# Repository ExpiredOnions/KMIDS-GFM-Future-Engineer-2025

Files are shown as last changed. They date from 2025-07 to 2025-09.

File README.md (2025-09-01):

# Hello! We are **Team KMIDS-GFM**.


# WRO - Future Engineers - Robotics Project Documentation

## Team Members

- **Chayanon Ninyawee (Garfield)**
- **Supakorn Sunthonthammarat (Pleum)**
- **Thammatouch Chantasarn (Kao)**

We are a team of dedicated students with a passion for robotics and innovation. This repository documents our full engineering process, including design, components used, development, testing, and coding of our robot.

## Table of Contents

<!-- toc -->

- [1. About the Project](#1-about-the-project)
- [2. Mobility Management](#2-mobility-management)
  - [2.1 Drive System](#21-drive-system)
  - [2.2 Steering](#22-steering)
- [3. Power and Sense Management](#3-power-and-sense-management)
  - [3.1 Power Source](#31-power-source)
  - [3.2 Sensor and Camera](#32-sensor-and-camera)
  - [3.3 Processing Units](#33-processing-units)
  - [3.4 Circuit Diagram](#34-circuit-diagram)
- [4. Obstacle Management](#4-obstacle-management)
  - [4.1 Open Challenge](#41-open-challenge)
  - [4.2 Obstacle Challenge](#42-obstacle-challenge)
  - [4.3 Parallel Parking](#43-parallel-parking)
  - [4.4 Extra: Converting Raw Lidar Data to Useful Data](#44-extra-converting-raw-lidar-data-to-useful-data)
- [5. Robot Design](#5-robot-design)
  - [5.1 Robot Images](#51-robot-images)
  - [5.2 Chassis Design](#52-chassis-design)
- [6. Performance Video](#6-performance-video)
- [7. Source Code](#7-source-code)
  - [7.1 Code Structure](#71-code-structure)
  - [7.2 Compilation / Upload Instructions](#72-compilation--upload-instructions)
    - [Dependencies](#dependencies)
    - [Raspberry Pi 5 Build](#raspberry-pi-5-build)
    - [Raspberry Pi Pico 2 Build & Upload](#raspberry-pi-pico-2-build--upload)
- [8. List of Components](#8-list-of-components)
- [9. 3D Printed Parts](#9-3d-printed-parts)
  - [9.1 Chassis & Core Structure](#91-chassis--core-structure)
  - [9.2 Motor & Transmission](#92-motor--transmission)
  - [9.3 Wheel & Axle Components](#93-wheel--axle-components)
  - [9.4 Steering Linkages](#94-steering-linkages)
  - [9.5 Miscellaneous](#95-miscellaneous)

<!-- tocstop -->

______________________________________________________________________

## 1. About the Project

This project focuses on designing, building, and programming an autonomous robot capable of completing a series of complex obstacle challenges as part of the WRO Future Engineers competition.

Team KMIDS-GFM was inspired by the challenge of applying engineering principles and problem-solving skills to creatively and efficiently solve complex problems. Pushing forward with our passion for innovation and hands-on learning.

Our goal is to design and build a reliable and efficient system that demonstrates our technical and collaborative skills while serving as a learning experience. We followed a systematic process, including brainstorming, researching, prototyping, testing, and iterating. We maintained detailed documentation for ease of knowledge sharing and a smoother workflow throughout the project.

Our robot is engineered using a custom modular chassis in a rear-wheel drive configuration, controlled using a Raspberry Pi 5 and a Raspberry Pi Pico 2. It utilises a combination of an LIDAR sensor and a fish-eye lens camera to provide an advanced system for obstacle detection and navigation.

Our objective is to create an intelligent robot that is capable of navigating through obstacles with pinpoint precision and speed.

______________________________________________________________________

## 2. Mobility Management

- **Drive System:** 2-wheel differential drive (rear wheels).
- **Steering:** Front-wheel steering using S0004m servo.

### 2.1 Drive System

[Motor: N20 Motor](https://shopee.co.th/product/627316253/26413874397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) 

<table>
  <tr>
    <td align="center" width="300" >
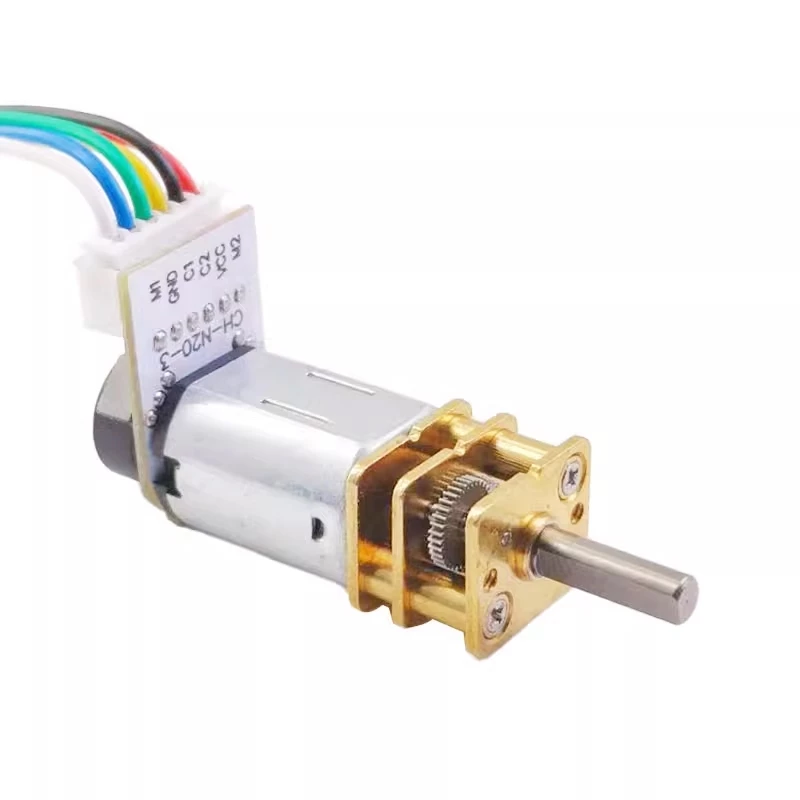
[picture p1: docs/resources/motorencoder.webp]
      
    </td>
    <td>
      <h3>Specifications:</h3>
      <ul>
        <li>Voltage: 6V </li>
        <li>No-load Speed: 500RPM </li>
        <li>Stall Torque 0.15kg-cm</li>
        <li>Current: 0.023A</li>
        <li>Gear Ratio: 1:100</li>
      </ul>
    </td>
  </tr>
</table>

**Reason for Selection:**

- It is compact and lightweight, allowing us to fit it into our robot easily.
- Provides moderate torque that is more than enough for the flat arena.
- Easy to use on the robot and integrate with other parts.

The N20 motor is equipped with an encoder to provide precise motion feedback, ensuring the robot’s movements are accurate. The motor drives the rear wheels through a LEGO differential gear system, which allows the robot to maintain smooth and balanced turns even at higher speeds. By distributing torque between the two wheels, the differential minimises wheel slip and ensures stability during sharp manoeuvres.
The integration of encoders with the N20 motors provides real-time feedback for closed-loop control, enabling precise speed regulation and consistent lap performance. Although the torque of the N20 is modest, the combination with the differential gear makes it well-suited for the flat and predictable competition arena, striking a balance between efficiency, stability, and mechanical simplicity.

**Mounting:**

- Installed using 3D-printed motor clamps screwed to a detachable motor plate that is placed above the differential gear compartment. This will allow for future changes to accommodate bigger motors and gears. (./FreeCAD-Files/Assembly/mesh_export/MotorPlate_1x.stl)
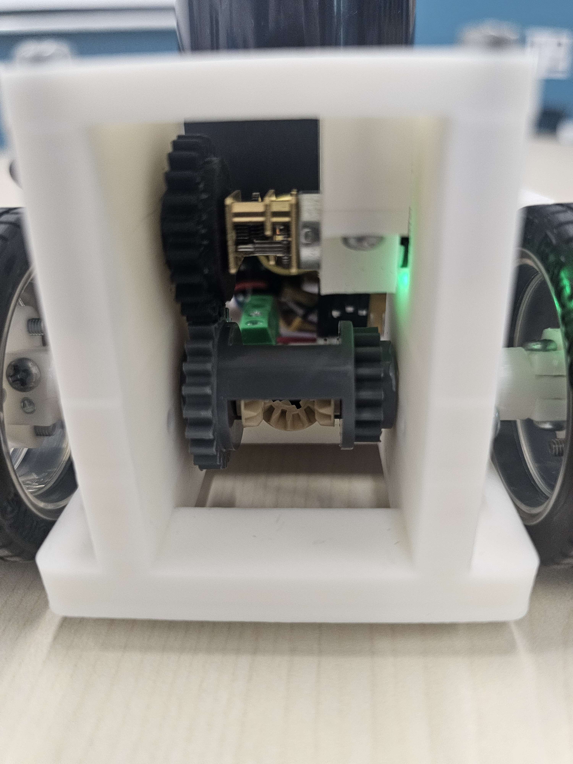
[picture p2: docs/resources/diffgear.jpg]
diff gear
  
- Wires connected to Raspberry Pi Pico 2.
- Rubber wheels are screwed onto the motor shaft.

**Considerations:**
To reach a faster speed, we can upgrade the N20 motor to the N30, which is the easiest upgrade, providing an overall improvement in speed and torque. However, the N30 motor is typically larger and such, might need extra modifications to the robot's chassis and motor clamp to fit properly. It also generally operates at higher voltages and currents, so the power supply needs to be modified to support this upgrade.

### 2.2 Steering

We considered many steering systems, but following our design principle of precision, we decided to implement Ackermann steering geometry to better replicate the precise turning behaviour of real-world vehicles. Unlike simpler systems, Ackermann steering has the advantage of smoother turns by moving each wheel at different angles in a turn, reducing the slippage of the tires and improving turn accuracy.

The fundamental principle of Ackermann geometry involves positioning the steering linkage so that a line drawn through both front wheels intersects the rear axle of the robot.

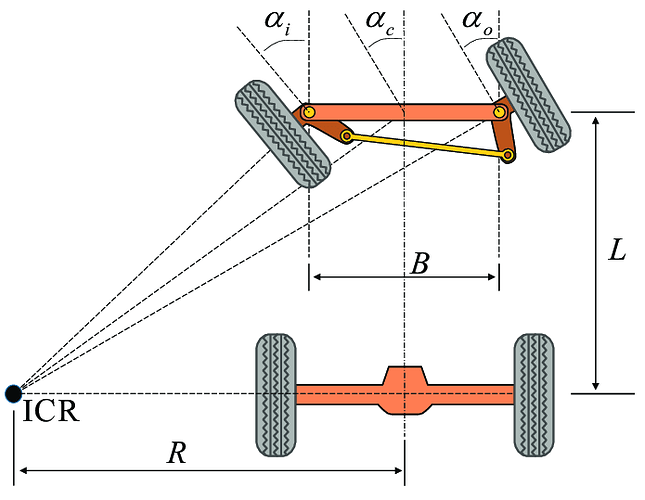
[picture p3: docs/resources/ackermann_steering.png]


While this steering geometry is complex to implement, we believe that the advantages it provides are important, especially in obstacle navigation and parking, where precise control and minimized turning radius are essential. It enables smoother manoeuvring and accurate alignment in narrower spaces.

Our implementation involves designing a custom 3D-printed Ackermann steering mechanism. Using CAD to design the mechanism gives us the flexibility to experiment with pivot points and steering angles. Although true Ackermann geometry is difficult to implement at our robot's scale, we tried to approximate the behavior iteratively by adjusting the servo horns and angles in CAD and prototyping by making smaller changes if it doesn't suit our desired behavior.

**Calibration and Implementation**

To make sure the steering angle performed correctly, we carried out an iterative calibration process:

- We manually adjusted the servo horn angle and linkage positions step by step in FreeCAD until the wheels aligned at the desired steering angle.
- After each adjustment, we observed whether the wheels tracked correctly in both directions.
- Once the optimal angle is reached, we make sure to model the steering mechanism around the angle.



[Servo: S0004m](https://shopee.co.th/%E0%B9%80%E0%B8%8B%E0%B8%AD%E0%B8%A3%E0%B9%8C%E0%B9%82%E0%B8%A7%E0%B8%94%E0%B8%B4%E0%B8%88%E0%B8%B4%E0%B8%97%E0%B8%B1%E0%B8%A5-%E0%B8%82%E0%B8%9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) 

<table>
  <tr>
    <td align="center" width="300" >
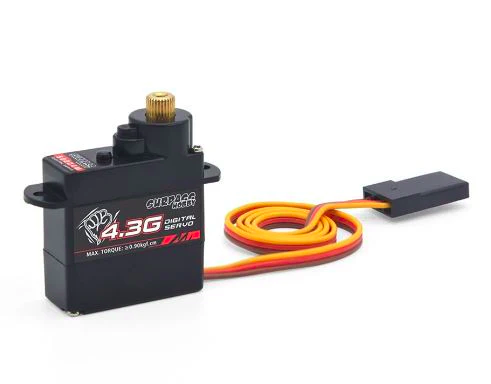
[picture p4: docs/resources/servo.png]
      
    </td>
    <td> 
      <h3>Specifications:</h3>
      <ul>
          <li>Rated Torque: 0.6kgf-cm</li>
          <li>Speed: 0.09sec/60°</li>
          <li>Voltage: 5V</li>
          <li>Gearing: Plastic</li>
          <li>Type: Digital </li>
      </ul>
    </td>
  </tr>
</table>

**Reason for Selection:**

- The small size and PWM interface make it easy to control via Raspberry Pi Pico 2.
- It has sufficient torque to steer the front wheels responsively.
- It has balanced speed and stability during turns and lane changes.
- This servo is widely used in hobby robotics, and as such, there is much available documentation and mounting kits.

**Mounting:**

- Screwed directly into a platform plate in front of the chassis into the platform plate.

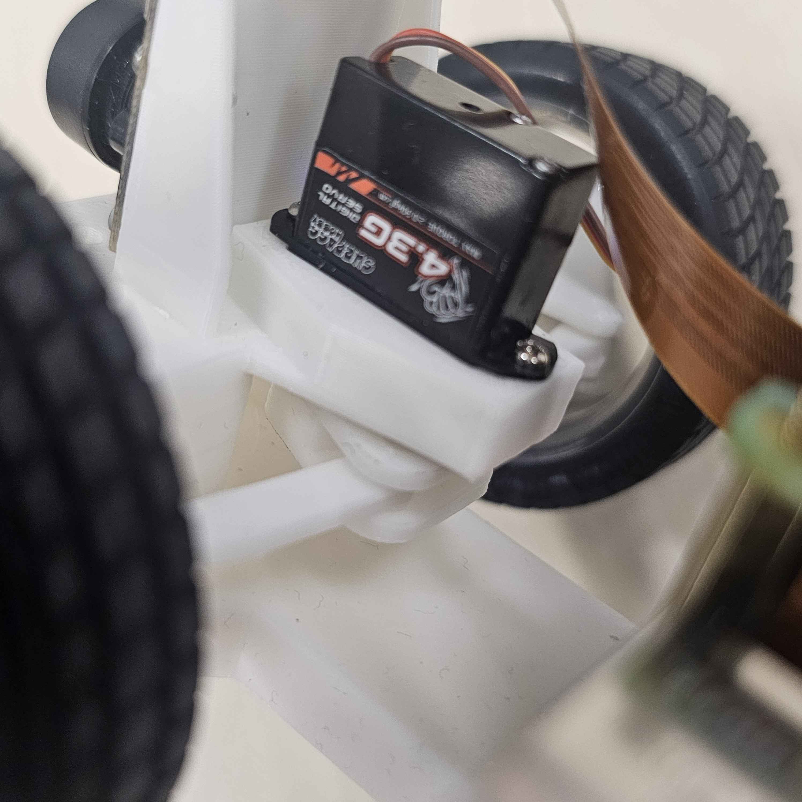
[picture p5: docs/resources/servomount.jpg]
Servo Mounting


**Considerations**
While the servo used is adequate for the task, it can still be replaced with something more precise. We plan to upgrade to a high-resolution digital servo with a narrower deadband and metal gears for more accurate movement. By also integrating a PWM driver such as the PCA9685, we gain 12-bit resolution control, which gives the robot the ability to make finer adjustments than the Raspberry Pi’s native PWM.

______________________________________________________________________

## 3. Power and Sense Management

### 3.1 Power Source

[18650 Lithium-Ion Battery](https://th.cytron.io/p-3.7v-2000mah-li-ion-battery)

<table>
  <tr>
    <td align="center" width="300" >
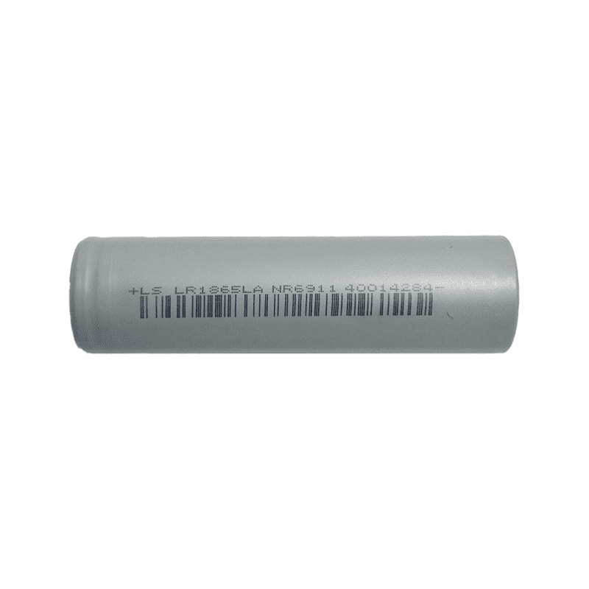
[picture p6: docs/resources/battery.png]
      
    </td>
    <td>
      <h3>Specifications:</h3>
      <ul>
          <li>Capacity: 2000 mAh</li>
          <li>Normal voltage: 3.7V</li>
          <li>Standard discharge: 10A </li>
          <li>Weight: 48g</li>
      </ul>
    </td>
  </tr>
</table>

The power and sensor systems are crucial to the vehicle's ability to navigate the challenges of the competition. For this project, the vehicle is powered by a [EP-0136 Raspberry Pi UPS](https://wiki.52pi.com/index.php?title=EP-0136) (Uninterruptible Power Supply) in our vehicle, with 2x 18650 Lithium-Ion as the energy source. The UPS maintains a stable 5V output to the Raspberry Pi 5 even though there are fluctuations. It also has built-in charging and voltage regulation circuits, allowing continuous operation while also recharging the batteries when external power is connected.
The batteries are connected in series to provide a nominal voltage of 7.4V and a combined capacity of around 4000 mAh, depending on the cells used. This setup is capable of delivering a continuous current of around 20 Amps, which is sufficient to supply to the robot for various tasks. This setup ensures that the Raspberry Pi won't shut down unexpectedly, allowing uninterrupted data processing and decision-making throughout the run.

The motors, however, require a higher voltage — at least 6V, and to ensure reliable performance, the N20 motor power is supplied through a step-up converter that increases 5V to 12V. Because the motor power is separate from the Raspberry Pi, the standard on/off switch could not fully control the system. To solve this, a MOSFET and a 4.4 kΩ resistor were added between the gate and source, with the drain connected to the negative side of the step-up converter. This allows the robot to be safely powered on and off while supplying sufficient power to both the Raspberry Pi and the motors.

The onboard processing unit, the Raspberry Pi 5, serves as the vehicle's brain. Raspberry Pi recommends a 5V 5A power supply. This is well within the limits of what the two batteries can provide.

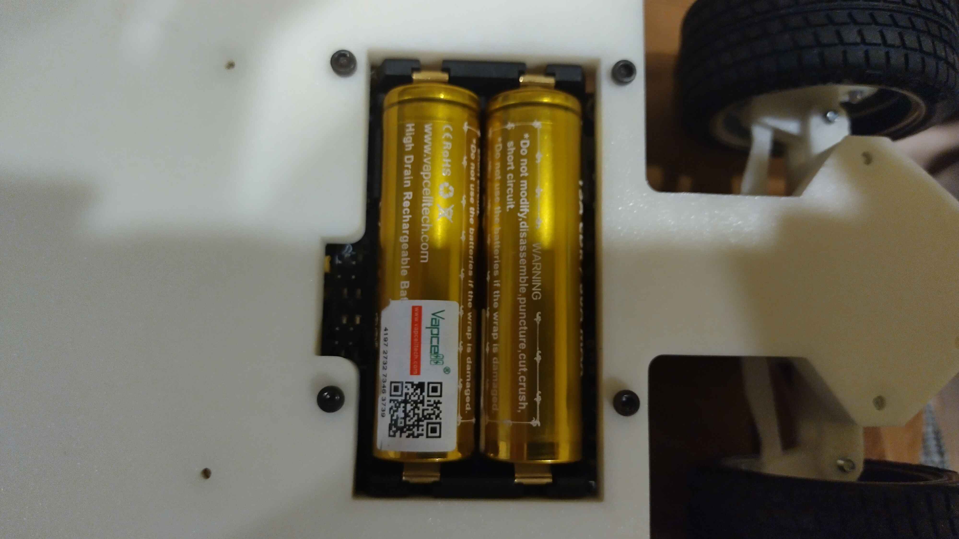
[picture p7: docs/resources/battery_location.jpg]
 

### 3.2 Sensor and Camera

[RPLIDAR C1](https://www.slamtec.com/en/C1)

<table>
  <tr>
    <td align="center" width="300" >
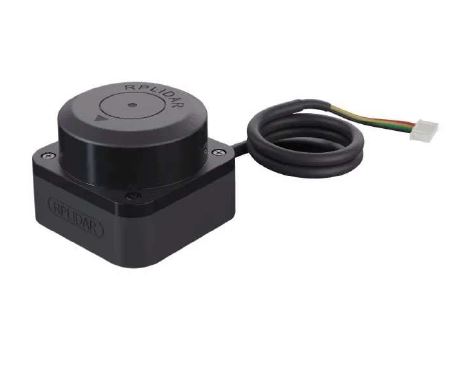
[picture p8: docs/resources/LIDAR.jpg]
      
    </td>
    <td>
      <h3>Specifications:</h3>
      <ul>
        <li>Distance Range:
          <ul>
            <li>White: 0.05~12m (70% Reflectivity)</li>
            <li>Black: 0.05~6m (10% Reflectivity)</li>
          </ul>
        </li>
        <li>Angle Resolution: 0.72°</li>
        <li>Sample Frequency: 8~12Hz (10Hz Typical)</li>
        <li>Range Accuracy: 15mm</li>
        <li>Discharge Rate: 30C</li>
        <br/><br/>
      </ul>
    </td>
  </tr>
</table>

**Reason for Selection:**

- **Precise distance measurement** of obstacles within a wide radius
- **360° scanning** makes it ideal for SLAM (Simultaneous Localisation and Mapping).
- **Compact size and lightweightness** allow easy fitting on our robot.
- **Fast sampling rate** allows real-time mapping and obstacle avoidance.

<!--FIXME: Add LIDAR_mount.png-->

[Fish Eye Lens Raspberry Pi 5MP IR Camera](https://th.cytron.io/p-fish-eye-lense-raspberry-pi-5mp-ir-camera?r=1&language=en-gb&gad_campaignid=18809653822)

<table >
  <tr>
    <td align="center" width="300" >
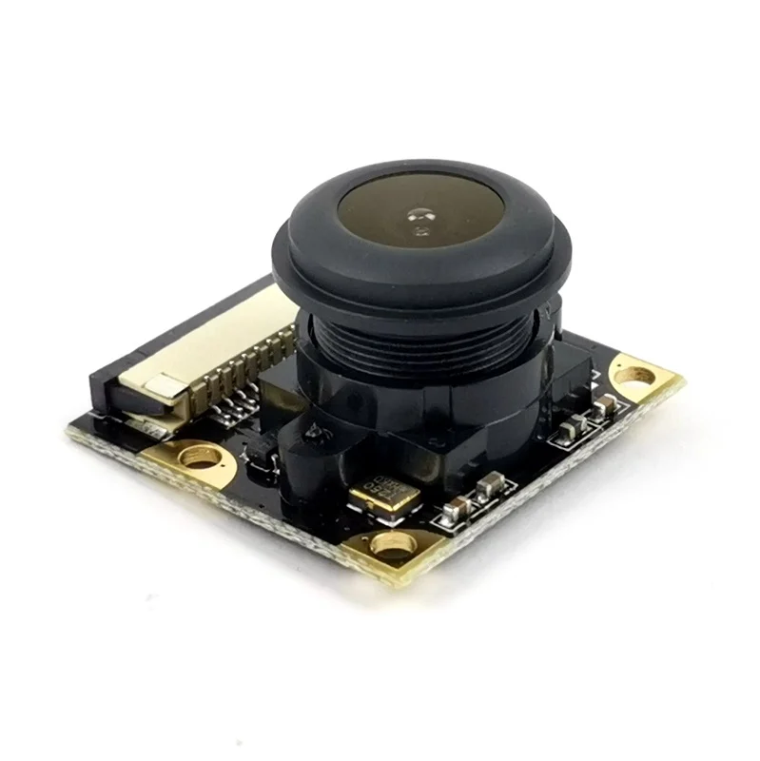
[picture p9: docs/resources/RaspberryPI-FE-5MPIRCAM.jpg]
      
    </td>
    <td >
      <h3>Specifications:</h3>
      <ul>
        <li>Voltage: 6V</li>
        <li>Resolution: 5MP </li>
        <li>Focal Length: Adjustable</li>
        <li>Image Sensor: OV5647</li>
        <li>Aperture: F2.35</li>
      </ul>
    </td>
  </tr>
</table>

**Reason for Selection:**

- **130° wide field of view** captures a large area for tracking.
- **Infrared compatibility** enables low-light vision.
- **High-resolution (5MP)** provides a clear image for the robot.
- **Compact size** fits well on our robot.

This setup allows for a wide-angle view, enhancing environmental awareness during both the Open Challenge and Obstacle Challenge. The camera identifies course elements such as walls, pillars, colored markers, parking spaces, and lane lines.

- Detect and differentiate wall positions.

- Identify pillar colours and types.

- Recognise parking zones.

- Track path lines and boundaries.

### 3.3 Processing Units

[Single Board Computer: Raspberry Pi 5](https://gammaco.com/gammaco/Raspberry_Pi_GB_89RD014.html)

<table>
  <tr>
    <td align="center" width="300" >
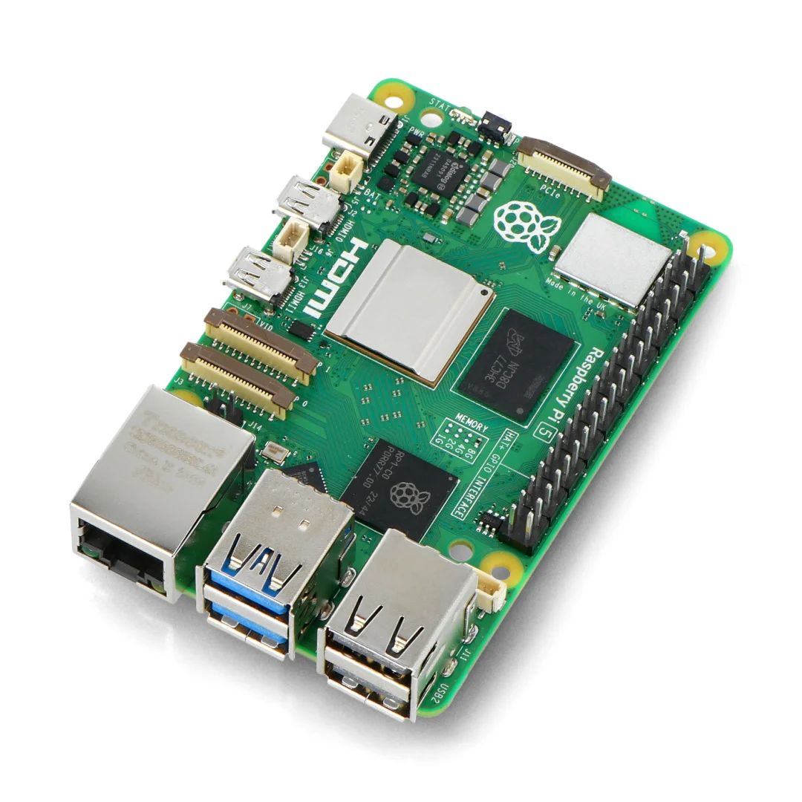
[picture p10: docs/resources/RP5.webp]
INSERT RP5
      
    </td>
    <td>
      <h3>Specifications:</h3>
      <ul>
        <li>Quad-core Arm Cortex-A76 CPU @ 2.4GHz</li>
        <li>8GB LPDDR4X RAM</li>
        <li>Dual 4K HDMI output (60fps)</li>
        <li>PCIe 2.0 support via FPC connector</li>
        <li>2x USB 3.0 ports, 2x USB 2.0 ports</li>
      </ul>
    </td>
  </tr>
</table>

[Raspberry Pi Pico 2](https://th.cytron.io/p-raspberry-pi-pico2-board)

<table>
  <tr>
    <td align="center" width="300" >
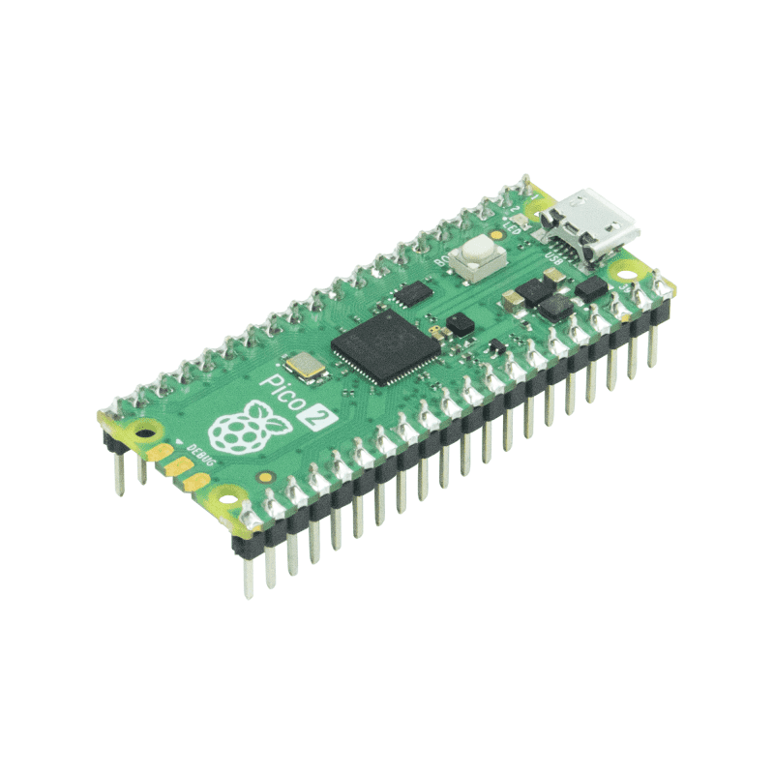
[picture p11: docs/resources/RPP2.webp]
INSERT RPP2
      
    </td>
    <td>
      <h3>Specifications:</h3>
      <ul>
        <li>Dual ARM Cortex-M33</li>
        <li>4 MB QSPI flash memory</li>
        <li>520KB SRAM</li>
        <li>2.4GHz 802.11n wireless LAN</li>
        <li>26 multi-function GPIO pins</li>
      </ul>
    </td>
  </tr>
</table>

### 3.4 Circuit Diagram

**Wiring Diagram:**

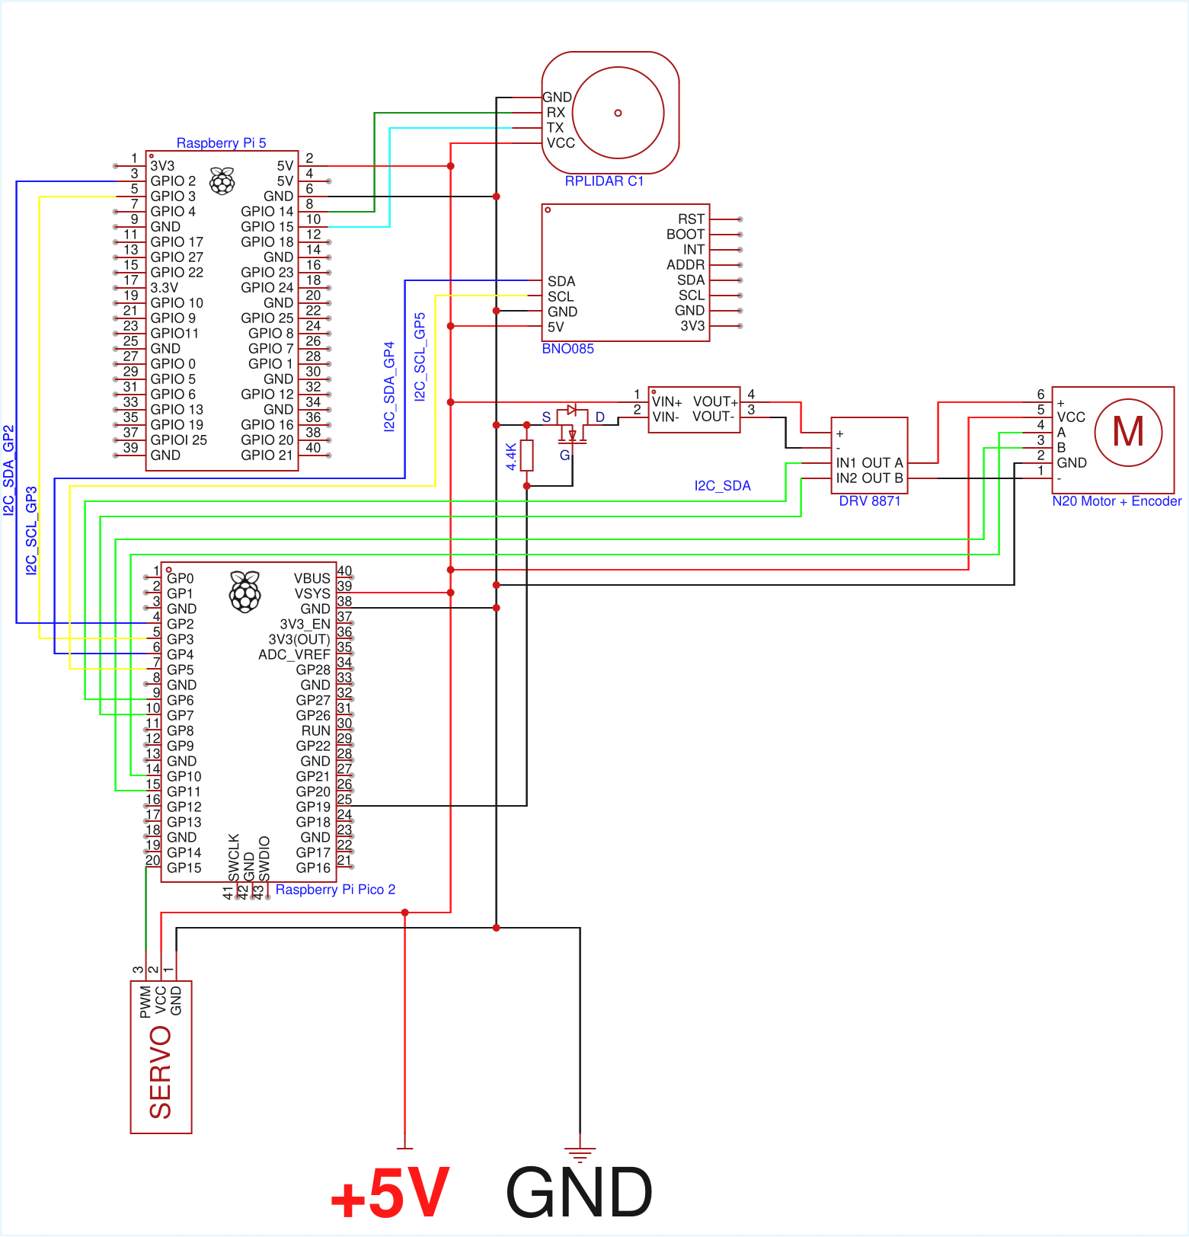
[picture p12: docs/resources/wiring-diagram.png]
Wiring diagram pic


______________________________________________________________________

## 4. Obstacle Management

There are two challenges in this competition:

- The **open challenge** involves the robot completing three full laps around the field without touching the wall. The size of each side of the field and the direction in which the car drives are randomised.
- The **obstacle challenge** requires the robot to complete three laps whilst avoiding the traffic signs. If the sign is red, then the robot must traverse on the right side and if the pillar is green, the robot must traverse on the left. The direction in which the car drives and the placement of the signs are randomised. After the third lap, the car must find the parking area and park in the area without touching the surroundings barriers around it.

Our implementation relies heavily on the RPLIDAR C1 sensor and the fish-eye lens camera for continuous environment scanning, which helps the algorithm decide the movement of the robot.

We divide the strategy into three phases:

- Open Challenge
- Obstacle Challenge
- Parallel Parking Manoeuvre

### 4.1 Open Challenge

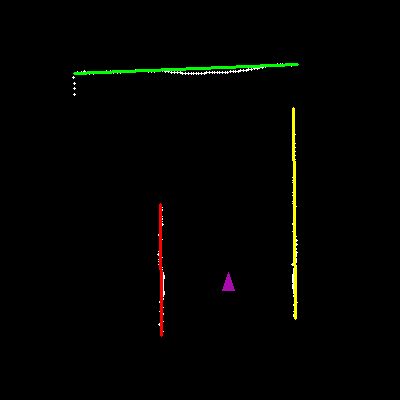
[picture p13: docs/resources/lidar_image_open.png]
Robot navigating Open Challenge
\
*Figure: Example of robot sensing walls and navigating the field.*

The Open Challenge requires the robot to complete three laps around the arena without touching the walls. The driving direction is randomised at the start, so relying on pre-programmed movements is not feasible

The robot determines which direction to turn by analysing the walls detected around it. The algorithm works as follows:

1. **Check for empty walls:**

   - If there are no front walls or no side walls, the function returns `std::nullopt` because it cannot determine a turn direction.

1. **Identify the closest front wall:**

   - Compares all front wall line segments and selects the one with the highest midpoint (largest Y value).
   - Determines the left and right points of this front wall based on their X coordinates.

1. **Evaluate left walls:**

   - Finds the "higher" point of each left wall line segment.
   - Uses `perpendicularDirection` and `perpendicularDistance` to determine if a left turn is feasible.
   - Returns `COUNTER_CLOCKWISE` if a left turn is clear, or `CLOCKWISE` if blocked.

1. **Evaluate right walls:**

   - Similarly, checks the right wall line segments.
   - Returns `CLOCKWISE` if a right turn is clear, or `COUNTER_CLOCKWISE` if blocked.

1. **Fallback:**

   - If no rules match, returns `std::nullopt`, indicating that the turn direction cannot be determined.

<details>
<summary>Click here to show C++ code</summary>

getTurnDirection code (from [lidar_processor.h](code/raspberry-pi-5/src/processors/lidar/lidar_processor.h) / [lidar_processor.cpp](code/raspberry-pi-5/src/processors/lidar/lidar_processor.cpp)) 

```cpp
/**
 * @brief Determine the robot's turn direction based on relative walls.
 *
 * @param walls Resolved or candidate walls around the robot.
 * @return Optional RotationDirection; empty if turn direction can't be determined.
 */
std::optional<RotationDirection> getTurnDirection(const RelativeWalls &walls) {
    if (walls.frontWalls.empty()) return std::nullopt;
    if (walls.leftWalls.empty() && walls.rightWalls.empty()) return std::nullopt;

    // Pick the highest front line
    const LineSegment *frontLine = &walls.frontWalls[0];
    float frontMidY = (frontLine->y1 + frontLine->y2) / 2.0f;
    for (const auto &line : walls.frontWalls) {
        float midY = (line.y1 + line.y2) / 2.0f;
        if (midY > frontMidY) {
            frontLine = &line;
            frontMidY = midY;
        }
    }

    // Determine left and right points of the front line
    float frontLeftX, frontLeftY, frontRightX, frontRightY;
    if (frontLine->x1 < frontLine->x2) {
        frontLeftX = frontLine->x1;
        frontLeftY = frontLine->y1;
        frontRightX = frontLine->x2;
        frontRightY = frontLine->y2;
    } else {
        frontLeftX = frontLine->x2;
        frontLeftY = frontLine->y2;
        frontRightX = frontLine->x1;
        frontRightY = frontLine->y1;
    }

    // Check left walls
    for (const auto &leftLine : walls.leftWalls) {
        float leftHigherX, leftHigherY;
        if (leftLine.y1 < leftLine.y2) {
            leftHigherX = leftLine.x1;
            leftHigherY = leftLine.y1;
        } else {
            leftHigherX = leftLine.x2;
            leftHigherY = leftLine.y2;
        }

        // Check for left wall that is far away in x direction from front wall
        float dir = leftLine.perpendicularDirection(frontLeftX, frontLeftY);
        if (dir > 90.0f && dir < 270.0f) {
            if (leftLine.perpendicularDistance(0.0f, 0.0f) > 1.70f) return RotationDirection::COUNTER_CLOCKWISE;

            continue;
        }

        if (frontLine->perpendicularDistance(leftHigherX, leftHigherY) < 0.30) return RotationDirection::CLOCKWISE;

        if (leftLine.perpendicularDistance(frontLeftX, frontLeftY) > 0.30f) {
            float dir = leftLine.perpendicularDirection(frontLeftX, frontLeftY);
            if (dir > 270.0f || dir < 90.0f) return RotationDirection::COUNTER_CLOCKWISE;
        }
    }

    // Check right walls
    for (const auto &rightLine : walls.rightWalls) {
        float rightHigherX, rightHigherY;
        if (rightLine.y1 < rightLine.y2) {
            rightHigherX = rightLine.x1;
            rightHigherY = rightLine.y1;
        } else {
            rightHigherX = rightLine.x2;
            rightHigherY = rightLine.y2;
        }

        // Check for right wall that is far away in x direction from front wall
        float dir = rightLine.perpendicularDirection(frontRightX, frontRightY);
        if (dir > 270.0f || dir < 90.0f) {
            if (rightLine.perpendicularDistance(0.0f, 0.0f) > 1.70f) return RotationDirection::CLOCKWISE;

            continue;
        }

        if (frontLine->perpendicularDistance(rightHigherX, rightHigherY) < 0.30) return RotationDirection::COUNTER_CLOCKWISE;

        if (rightLine.perpendicularDistance(frontRightX, frontRightY) > 0.30f) {
            float dir = rightLine.perpendicularDirection(frontRightX, frontRightY);
            if (dir > 90.0f && dir < 270.0f) return RotationDirection::CLOCKWISE;
        }
    }

    return std::nullopt;  // unknown if no rule matched
}
```

</details>

### 4.2 Obstacle Challenge

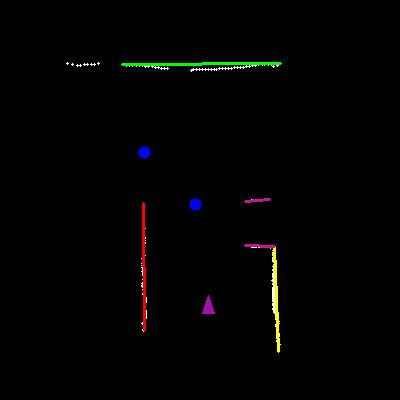
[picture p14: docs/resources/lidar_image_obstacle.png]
LIDAR view

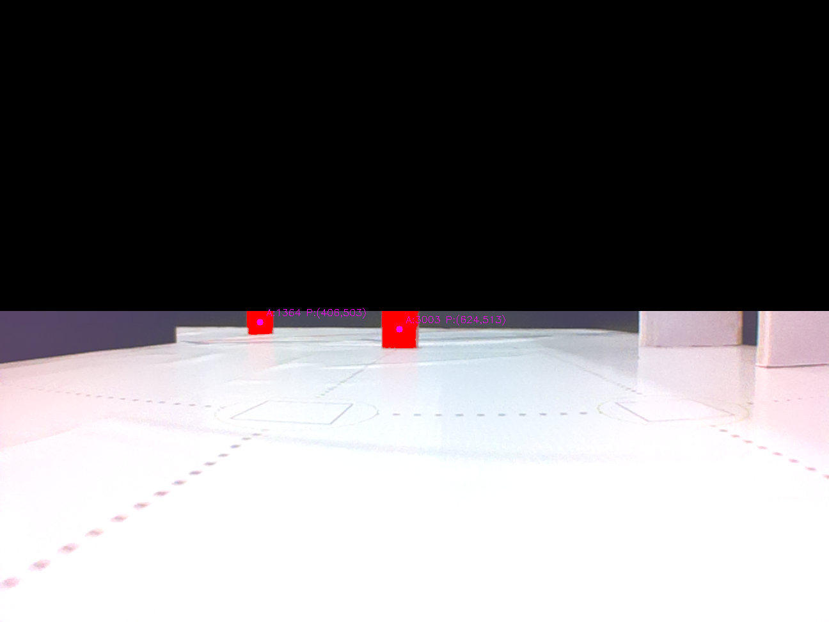
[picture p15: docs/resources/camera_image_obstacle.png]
Camera view


*Figure: Example of the robot detecting traffic lights.*

The Obstacle Challenge requires the robot to navigate the arena while avoiding obstacles and detecting traffic lights. The robot combines LiDAR and camera data to make real-time decisions. The main processing steps are:

1. **Determine turn direction**

   - Uses the same algorithm as in the Open Challenge to decide whether to turn CLOCKWISE or COUNTER_CLOCKWISE based on the surrounding walls.
   - If no clear direction is detected, the default is CLOCKWISE.

1. **Convert LiDAR data to Cartesian coordinates**

   - LiDAR points that are too close (< 0.005 m), too far (> 3.2 m), or outside the forward scanning range are ignored.
   - Converts polar coordinates (distance, angle) to Cartesian coordinates relative to the robot.

1. **Filter points based on walls and turn direction**

   - Depending on the current turn direction, left, right, and far walls are used to remove points that are too close to obstacles.
   - Thresholds (`outerEdge = 0.30 m`, `innerEdge = 0.70 m`) define valid regions for candidate traffic lights.

1. **Cluster nearby LiDAR points**

   - Points within `distanceThreshold` (default 0.05 m) are grouped together.
   - Each cluster is averaged to generate a candidate traffic light location.

1. **Filter camera colors**

   - The camera frame is converted to HSV colour space.
   - Thresholded for red, green, and pink colours.
   - The top 50% of the frame is blacked out to reduce noise from the ceiling or irrelevant background.
   - Contours are extracted, and only those larger than the `areaThreshold` are kept.

1. **Combine camera and LiDAR data**

   - For each detected camera block (red/green), find the closest LiDAR point within a maximum allowed horizontal angle difference.
   - Only the nearest point along the ray is matched to prevent duplicate detections.
   - Returns a vector of `TrafficLightInfo` containing both the LiDAR location and the camera block information.

1. **Decision making**

   - Using the combined traffic light data, the robot can identify which traffic light is relevant for its current path.
   - Integrates turn direction, obstacle positions, and traffic light locations to navigate safely and efficiently.

<details>
<summary>Click here to show C++ code for Obstacle Challenge processing</summary>

getTrafficLightPoints code (from [lidar_processor.h](code/raspberry-pi-5/src/processors/lidar/lidar_processor.h) / [lidar_processor.cpp](code/raspberry-pi-5/src/processors/lidar/lidar_processor.cpp)) <!--TODO: Add link to the actual file-->

```cpp
/**
 * @brief Detect traffic light points from LiDAR data and resolved walls.
 *
 * @param timedLidarData LiDAR scan data with timestamps.
 * @param resolveWalls Resolved walls around the robot.
 * @param turnDirection Optional turn direction of the robot (if has no value, assume CLOCKWISE).
 * @param distanceThreshold Maximum distance between points to cluster into a single traffic light point.
 * @return Vector of 2D points representing detected traffic light locations.
 */
std::vector<cv::Point2f> getTrafficLightPoints(
    const TimedLidarData &timedLidarData,
    const ResolvedWalls resolveWalls,
    std::optional<RotationDirection> turnDirection,
    float distanceThreshold
) {
    // Convert polar to Cartesian (in meters)
    std::vector<cv::Point2f> points;
    points.reserve(timedLidarData.lidarData.size());

    for (const auto &node : timedLidarData.lidarData) {
        // TODO: Change this value to fit the actual robot
        if (node.distance < 0.005) continue;
        if (node.distance > 3.200) continue;
        if (node.angle > 5 && node.angle < 175 && node.distance > 0.700) continue;

        float rad = node.angle * static_cast<float>(M_PI) / 180.0f;

        float lidarX = node.distance * std::sin(rad);
        float lidarY = node.distance * std::cos(rad);
        float x, y;
        lidarToCartesian(lidarX, lidarY, x, y);

        points.emplace_back(x, y);
    }

    std::vector<cv::Point2f> filteredPoints;
    for (auto &point : points) {
        if (not resolveWalls.frontWall) return {};
        float frontDistance = resolveWalls.frontWall->perpendicularDistance(point.x, point.y);

        std::optional<LineSegment> outerWall, innerWall, farOuterWall;
        if (turnDirection.value_or(RotationDirection::CLOCKWISE) == RotationDirection::CLOCKWISE) {
            outerWall = resolveWalls.leftWall;
            innerWall = resolveWalls.rightWall;

            farOuterWall = resolveWalls.farRightWall;
        } else {
            outerWall = resolveWalls.rightWall;
            innerWall = resolveWalls.leftWall;

            farOuterWall = resolveWalls.farLeftWall;
        }

        float outerDistance;
        if (outerWall) {
            outerDistance = outerWall->perpendicularDistance(point.x, point.y);
        } else if (innerWall) {
            outerDistance = 1.00f - innerWall->perpendicularDistance(point.x, point.y);
        } else {
            return {};
        }

        // TODO: Clean up this magic number
        const float outerEdge = 0.30f;
        const float innerEdge = 0.70f;

        if (farOuterWall) {
            float outerFarDistance = farOuterWall->perpendicularDistance(point.x, point.y);

            if (frontDistance < outerEdge or frontDistance > 3.00f - outerEdge or outerDistance < outerEdge or outerFarDistance < outerEdge)
                continue;
            if (frontDistance > innerEdge and outerDistance > innerEdge and outerFarDistance > innerEdge) continue;
        } else {
            if (frontDistance < outerEdge or frontDistance > 3.00f - outerEdge or outerDistance < outerEdge or
                outerDistance > 3.00f - outerEdge)
                continue;
            if (frontDistance > innerEdge and outerDistance > innerEdge) continue;
        }

        filteredPoints.push_back(point);
    }

    std::vector<cv::Point2f> averages;
    if (filteredPoints.empty()) return averages;

    std::vector<cv::Point2f> currentCluster;
    currentCluster.push_back(filteredPoints[0]);

    for (size_t i = 1; i < filteredPoints.size(); ++i) {
        cv::Point2f p1 = currentCluster.back();
        cv::Point2f p2 = filteredPoints[i];

        float dist = std::hypot(p2.x - p1.x, p2.y - p1.y);

        if (dist < distanceThreshold) {
            currentCluster.push_back(p2);
        } else {
            // compute average for current cluster
            float sumX = 0, sumY = 0;
            for (auto &p : currentCluster) {
                sumX += p.x;
                sumY += p.y;
            }
            averages.emplace_back(sumX / currentCluster.size(), sumY / currentCluster.size());

            // start new cluster
            currentCluster.clear();
            currentCluster.push_back(p2);
        }
    }

    // handle last cluster
    if (!currentCluster.empty()) {
        float sumX = 0, sumY = 0;
        for (auto &p : currentCluster) {
            sumX += p.x;
            sumY += p.y;
        }
        averages.emplace_back(sumX / currentCluster.size(), sumY / currentCluster.size());
    }

    return averages;
}
```

filterColors code (from [lidar_processor.h](code/raspberry-pi-5/src/processors/lidar/lidar_processor.h) / [lidar_processor.cpp](code/raspberry-pi-5/src/processors/lidar/lidar_processor.cpp)) <!--TODO: Add link to the actual file-->

```cpp
/**
 * @brief Filters an input frame for red, green, and pink colors and extracts contours.
 *
 * The input frame is converted to HSV color space, thresholded into binary masks
 * for each target color (red, green, pink), and processed to extract contour
 * centroids and areas. Contours smaller than the given area threshold are discarded.
 *
 * @param timedFrame Input frame with timestamp and image data.
 * @param areaThreshold Minimum area threshold (in pixels) to filter out small/noisy contours.
 * @return ColorMasks A struct containing masks and contour info for red, green, and pink.
 */
ColorMasks filterColors(const TimedFrame &timedFrame, double areaThreshold) {
    const cv::Mat &input = timedFrame.frame;

    CV_Assert(!input.empty());
    CV_Assert(input.type() == CV_8UC3);

    // Fill the top part with black
    int topRows = static_cast<int>(input.rows * 0.50);
    input(cv::Rect(0, 0, input.cols, topRows)) = cv::Scalar(0, 0, 0);

    cv::Mat hsv;
    cv::cvtColor(input, hsv, cv::COLOR_BGR2HSV);

    // Red
    cv::Mat maskRed1, maskRed2, maskRed;
    cv::inRange(hsv, lowerRed1Light, upperRed1Light, maskRed1);
    cv::inRange(hsv, lowerRed2Light, upperRed2Light, maskRed2);
    cv::bitwise_or(maskRed1, maskRed2, maskRed);

    // Green
    cv::Mat maskGreen1, maskGreen2, maskGreen;
    cv::inRange(hsv, lowerGreen1Light, upperGreen1Light, maskGreen1);
    cv::inRange(hsv, lowerGreen2Light, upperGreen2Light, maskGreen2);
    cv::bitwise_or(maskGreen1, maskGreen2, maskGreen);

    return {{extractContoursInfo(maskRed, areaThreshold), maskRed}, {extractContoursInfo(maskGreen, areaThreshold), maskGreen}};
}
```

combineTrafficLightInfo code (from [lidar_processor.h](code/raspberry-pi-5/src/processors/lidar/lidar_processor.h) / [lidar_processor.cpp](code/raspberry-pi-5/src/processors/lidar/lidar_processor.cpp)) <!--TODO: Add link to the actual file-->

```cpp
/**
 * @brief Combine camera block angles and LiDAR traffic light points.
 *
 * Only returns traffic lights that have a matching camera block based on horizontal angle.
 * The LiDAR points are assumed to be in the LiDAR coordinate frame, and the camera may be
 * offset relative to the LiDAR. The function accounts for this offset when computing angles.
 *
 * @param blockAngles Vector of camera BlockAngle (red/green blocks).
 * @param lidarPoints Vector of 2D points from LiDAR (traffic lights), in LiDAR coordinates.
 * @param cameraOffset Position of the camera relative to the LiDAR (x, y) in LiDAR coordinates.
 * @param maxAngleDiff Maximum allowed difference in angle (radians) to consider a camera block
 *                     as corresponding to a LiDAR point.
 * @return std::vector<TrafficLightInfo> Combined information for traffic lights that have
 *                                      matching camera blocks.
 */
std::vector<TrafficLightInfo> combineTrafficLightInfo(
    const std::vector<camera_processor::BlockAngle> &blockAngles,
    const std::vector<cv::Point2f> &lidarPoints,
    cv::Point2f cameraOffset,
    float maxAngleDiff
) {
    std::vector<TrafficLightInfo> results;
    std::vector<cv::Point2f> availableLidar = lidarPoints;

    for (const auto &block : blockAngles) {
        size_t bestIndex = std::numeric_limits<size_t>::max();
        float smallestDiff = std::numeric_limits<float>::max();
        float closestDistance = std::numeric_limits<float>::max();

        // Loop over all available LiDAR points
        for (size_t i = 0; i < availableLidar.size(); ++i) {
            const auto &lp = availableLidar[i];
            float dx = lp.x - cameraOffset.x;
            float dy = lp.y - cameraOffset.y;

            float lidarAngle = std::atan2(dy, dx);  // radians
            float lidarAngleDeg = lidarAngle * 180.0f / M_PI;

            float angleDiff = std::abs(90.0f - block.angle - lidarAngleDeg);

            if (angleDiff <= maxAngleDiff) {
                float distanceAlongRay = std::sqrt(dx * dx + dy * dy);  // distance from camera to LiDAR point

                // Pick the closest along the ray (smallest distance)
                if (distanceAlongRay < closestDistance || angleDiff < smallestDiff) {
                    closestDistance = distanceAlongRay;
                    smallestDiff = angleDiff;
                    bestIndex = i;
                }
            }
        }

        if (bestIndex != std::numeric_limits<size_t>::max()) {
            results.push_back(TrafficLightInfo{availableLidar[bestIndex], block});
            availableLidar.erase(availableLidar.begin() + bestIndex);  // consume
        }
    }

    return results;
}
```

</details>

### 4.3 Parallel Parking

TBA. <!--TODO:-->

### 4.4 Extra: Converting Raw Lidar Data to Useful Data

TBA. <!--TODO:-->

______________________________________________________________________

## 5. Robot Design

### 5.1 Robot Images

<table>
  <tr>
    <td align="center">
      <b>Front View</b><br>
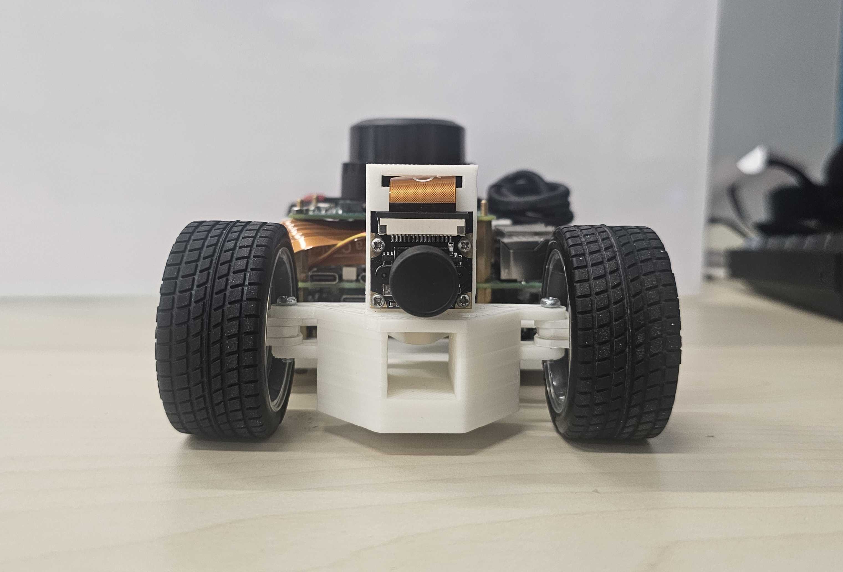
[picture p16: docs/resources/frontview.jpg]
      
    </td>
    <td align="center">
      <b>Back View</b><br>
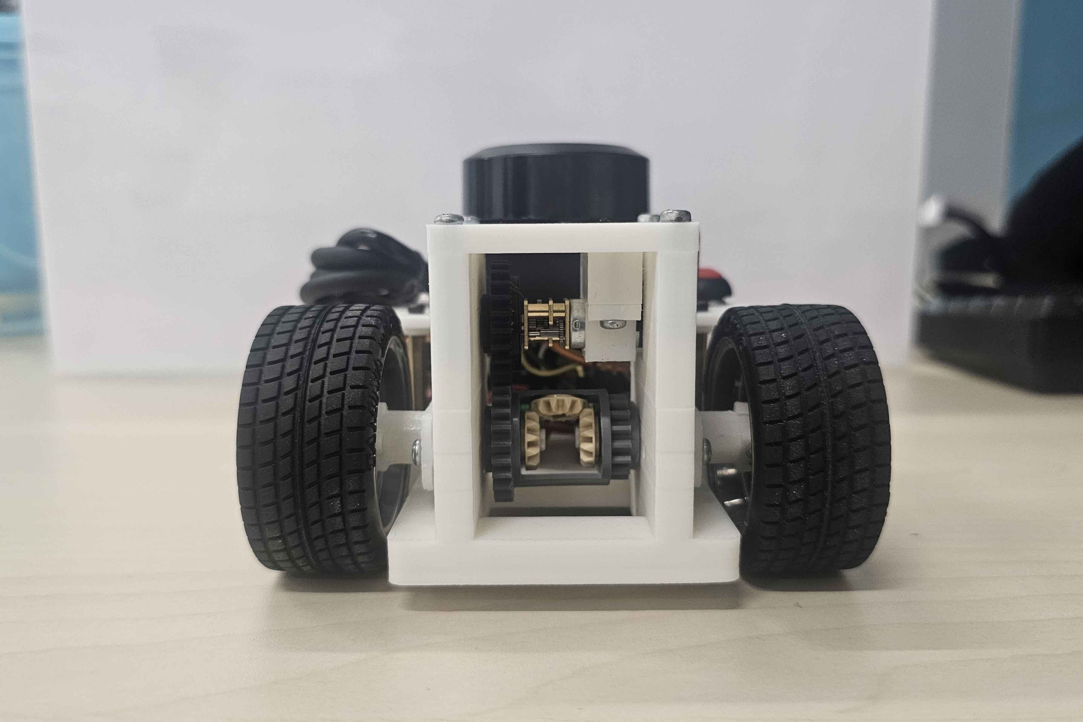
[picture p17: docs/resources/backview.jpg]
      
    </td>
    <td align="center">
      <b>Left Side View</b><br>
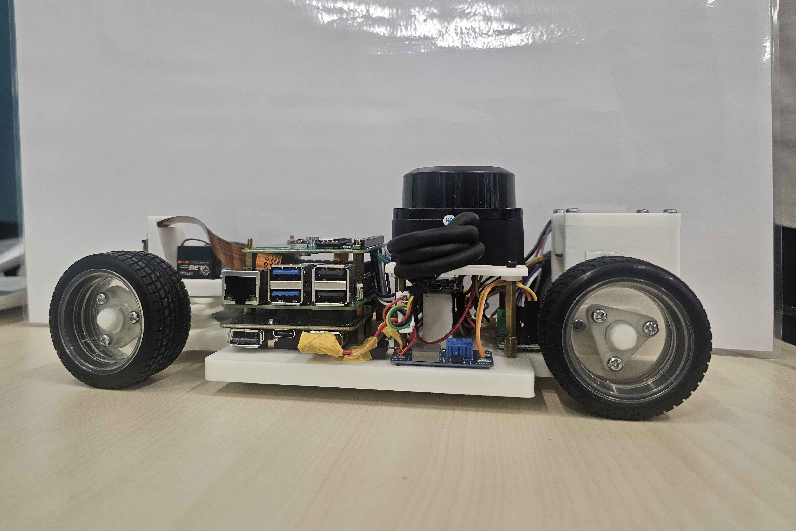
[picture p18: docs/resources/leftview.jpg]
      
    </td>
  </tr>
  <tr>
    <td align="center">
      <b>Right Side View</b><br>
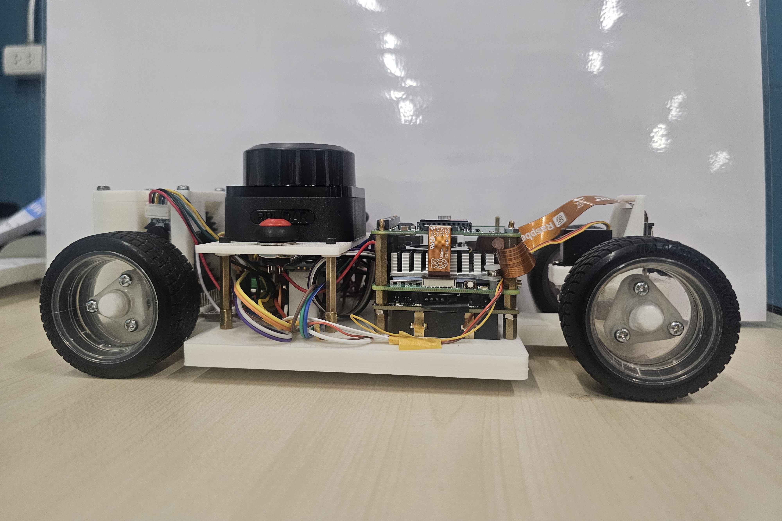
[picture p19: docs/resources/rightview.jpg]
      
    </td>
  <td align="center">
  <b>Top View</b><br>
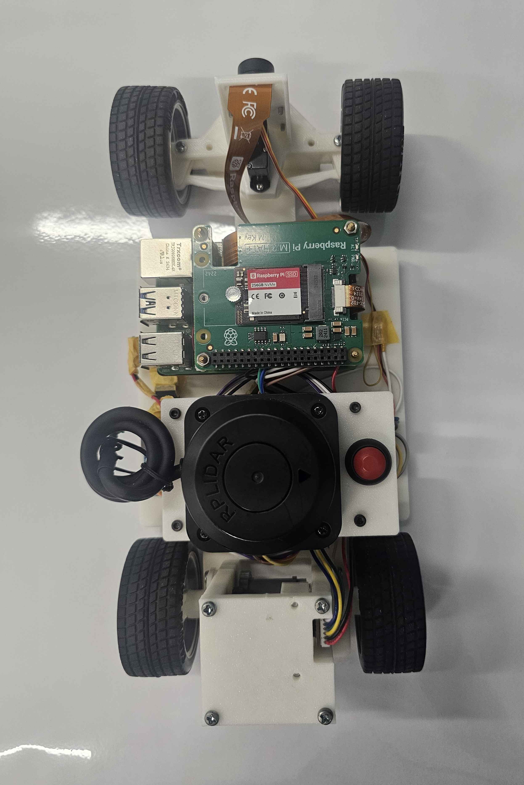
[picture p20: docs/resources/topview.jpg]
  
</td>
    <td align="center">
      <b>Bottom View</b><br>
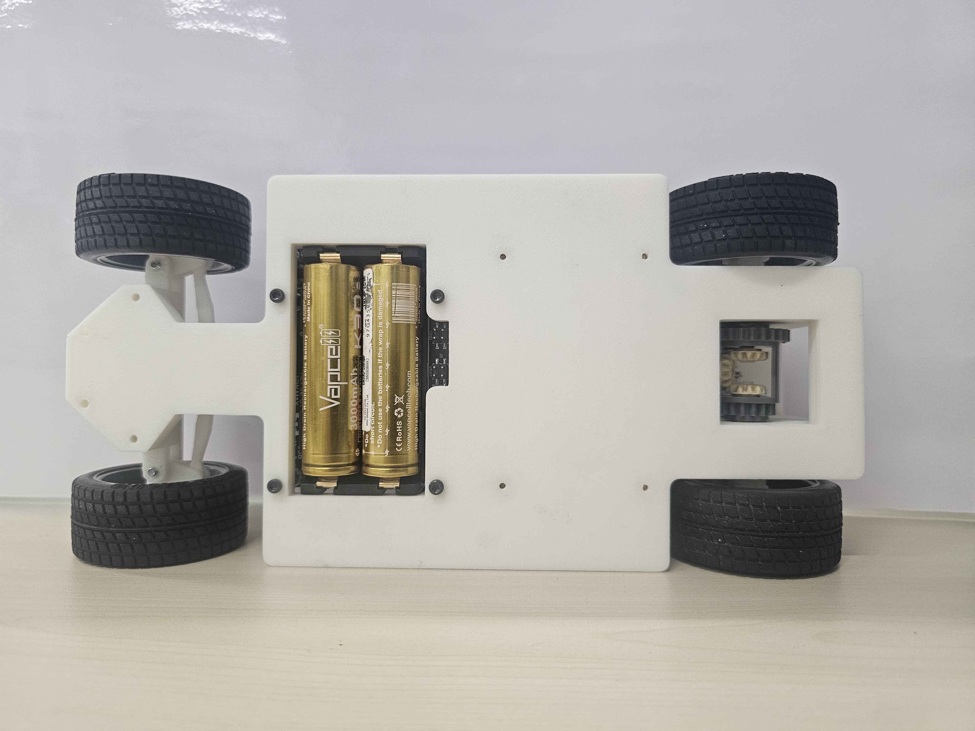
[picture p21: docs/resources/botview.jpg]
      
    </td>
  </tr>
</table>

### 5.2 Chassis Design

**Design Overview**

Our chassis was designed with a focus on weight and modularity. The goal is for our chassis to be a stable platform on which we can implement the steering geometry.

**Layout**
The layout of the chassis is made to fit the rear-mounted motors and front-mounted steering mechanism. Meanwhile, electronics and sensors are mounted in the centre for ease of wiring.

Our robot chassis was completely custom-designed and 3D printed using [esun PLA+](https://esun3dstore.com/products/pla-pro), which we found is easy to print with, offering a smoother texture while being lightweight and durable. The chassis was also designed with modularity in mind for additional future components and fixes, with reduced overhangs for printing ease. Apart from the main chassis, the drivetrain and steering modules are mounted on our 3D-printed detachable plates that can be fine-tuned during testing, other components, such as motor clamps, sensor brackets, are designed as independent printable components.

______________________________________________________________________

## 6. Performance Video

[Watch on YouTube](youtube.com/watch?v=7SNfU2ATe68&feature=youtu.be) 

#### | The video shows both the open and obstacle challenge

______________________________________________________________________

## 7. Source Code

### 7.1 Code Structure

All the code used in the robot can be found [here](code)
<!--TODO: Add link to the code-->

The project codebase is organised to separate different components, challenges, and hardware targets. The main folders are `raspberry-pi-5`, `raspberry-pi-pico-2`, and `shared`. The `shared` folder contains code used by both hardware targets.

```txt
repo-root
└─ code
   ├─ raspberry-pi-5
   │  ├─ apps
   │  │  ├─ challenges
   │  │  │  ├─ open_challenge      # Executable for open challenge
   │  │  │  └─ obstacle_challenge  # Executable for obstacle challenge
   │  │  ├─ log_viewer             # Applications to visualise logs
   │  │  ├─ scan_map_inner         # Inner map scanning tools
   │  │  ├─ scan_map_outer         # Outer map scanning tools
   │  │  ├─ test_camera            # Camera testing app
   │  │  ├─ test_i2c               # I2C communication testing
   │  │  ├─ test_lidar             # LIDAR testing app
   │  │  └─ test_lidar_cam         # Combined LIDAR + camera testing
   │  ├─ external
   │  │  ├─ lccv                   # External library (depends on libcamera)
   │  │  └─ rplidar_sdk            # RPLIDAR SDK (external, Make-based)
   │  ├─ scripts
   │  │  ├─ check_battery_status.py
   │  │  ├─ shutdown.sh
   │  │  └─ ups_shutdown.py
   │  ├─ src
   │  │  ├─ modules
   │  │  │  ├─ camera
   │  │  │  ├─ i2c_master
   │  │  │  ├─ lidar
   │  │  │  └─ pico2
   │  │  │     └─ CMakeLists.txt
   │  │  ├─ processors
   │  │  │  ├─ camera
   │  │  │  ├─ combined
   │  │  │  ├─ lidar
   │  │  │  └─ CMakeLists.txt
   │  │  ├─ types
   │  │  │  ├─ camera_struct.h
   │  │  │  ├─ lidar_struct.h
   │  │  │  ├─ pico2_struct.h
   │  │  │  └─ robot_pose_struct.h
   │  │  └─ utils
   │  │     ├─ direction
   │  │     ├─ log_reader
   │  │     ├─ logger
   │  │     ├─ pid_controller
   │  │     ├─ ring_buffer
   │  │     └─ CMakeLists.txt
   │  └─ CMakeLists.txt
   │  └─ build.sh
   │
   ├─ raspberry-pi-pico-2
   │  ├─ external
   │  │  ├─ BNO08x_Pico_Library
   │  │  └─ pico-sdk
   │  ├─ src
   │  │  ├─ modules
   │  │  │  ├─ controllers
   │  │  │  └─ i2c_slave
   │  │  ├─ utils
   │  │  │  └─ pid_controller
   │  │  └─ CMakeLists.txt
   │  ├─ main.cpp
   │  └─ CMakeLists.txt
   │  └─ build.sh
   │
   └─ shared                # Shared code used by both Pi 5 and Pi Pico
      ├─ i2c
      └─ types
```

**Notes on structure:**

- **`apps/`**: Executables for tests, challenges, and log visualization (Pi 5-specific).
- **`external/`**: Third-party libraries like LCCV, RPLIDAR SDK, Pico SDK.
- **`scripts/`**: System control scripts (shutdown, battery check, etc.).
- **`src/modules/`**: Hardware-specific functional modules.
- **`src/processors/`**: Data processing pipelines (camera, LIDAR, combined sensors).
- **`src/types/`**: Data structure headers for the local target.
- **`src/utils/`**: Utility classes (PID controllers, logging, ring buffers).
- **`shared/`**: Code reused by both `raspberry-pi-5` and `raspberry-pi-pico-2` (I2C handling, types).
- **`build.sh` & `CMakeLists.txt`**: Build scripts for each hardware target.

This structure allows Pi 5 and Pi Pico to share common code while keeping hardware-specific modules separate.

______________________________________________________________________

### 7.2 Compilation / Upload Instructions

This section describes how to build and run the project on the **Raspberry Pi 5** and **Raspberry Pi Pico 2**, including all dependencies.

______________________________________________________________________

#### Dependencies

**Git Submodules (must initialise and update recursively):**

```bash
git submodule update --init --recursive
```

**Raspberry Pi 5 specific:**

- **RPLIDAR SDK** – For LIDAR functionality.
- **LCCV** – Custom computer vision library that depends on **libcamera**.
- **System libraries (install separately):**
  - **OpenCV** – For camera image processing. The installation guide can be found [here](https://docs.opencv.org/4.x/d3/d52/tutorial_windows_install.html) <!--TODO: Add guide on how to install-->
  - **libcamera** – Required by LCCV for camera capture. The installation guide can be found [here](https://libcamera.org/getting-started.html)<!--TODO: Add guide on how to install-->

**Raspberry Pi Pico 2 specific:**

- **Pico SDK** – Required for building Pico firmware.
- **BNO08x_Pico_Library** – IMU library for Pico.

______________________________________________________________________

#### Raspberry Pi 5 Build

1. Go to the Pi 5 project directory:

```bash
cd ~/git/KMIDS-GFM-Future-Engineer-2025/code/raspberry-pi-5
```

2. Make the build script executable:

```bash
chmod +x build.sh
```

3. Build all targets:

```bash
./build.sh
```

4. Build a specific target (example: `open_challenge`):

```bash
./build.sh open_challenge
```

5. Executables are generated in the `build/` directory according to the CMake output settings.

______________________________________________________________________

#### Raspberry Pi Pico 2 Build & Upload

1. Go to the Pico project directory:

```bash
cd ~/git/KMIDS-GFM-Future-Engineer-2025/code/raspberry-pi-pico-2
```

2. Make the build script executable:

```bash
chmod +x build.sh
```

3. Build all targets:

```bash
./build.sh
```

4. Upload the compiled UF2 file to the Pico:

```bash
sudo picotool load build/gfm_pico_2.uf2 -f
```

> Note: The UF2 file path should match the output name specified in the Pico CMakeLists.txt.

______________________________________________________________________

## 8. List of Components

| Component | Quantity | Source/Supplier |
| --- | --- | --- |
| Raspberry Pi 5 | 1 | Gammaco |
| Raspberry Pi Pico 2 | 1 | Cytron |
| UPS EP-0136 | 1 | 52Pi |
| 18650 Lithium-Ion Battery | 2 | Cytron |
| RPLidar C1 | 1 | SLAMTEC |
| 5MP Fish Eye Camera | 1 | Cytron |
| BNO085 IMU | 1 | N/A |
| S0004m Servo | 1 | N/A |
| N20 DC Motor + encoder | 2 | N/A |
| DRV8871 | 1 | N/A |
| DC to DC Boost Step Up Module | 1 | N/A |
| N Channel MOSFET Transistor | 1 | N/A |
| 4.4 kΩ resistor | 1 | N/A |
| Wires | A lot | N/A |
| eSUN PLA+ Spool | 1-3 | eSUN |

______________________________________________________________________

<!--TODO:-->

## 9. 3D Printed Parts

### 9.1 Chassis & Core Structure
- [`Chassis_1x.stl`](FreeCAD-Files/Assembly/mesh_export/Chassis_1x.stl)
- [`FrontCover_1x.stl`](FreeCAD-Files/Assembly/mesh_export/FrontCover_1x.stl)
- [`AxleHolder_3x.stl`](FreeCAD-Files/Assembly/mesh_export/AxleHolder_3x.stl)

### 9.2 Motor & Transmission
- [`MotorGear_1x.stl`](FreeCAD-Files/Assembly/mesh_export/MotorGear_1x.stl)
- [`MotorHolder_1x.stl`](FreeCAD-Files/Assembly/mesh_export/MotorHolder_1x.stl)
- [`MotorPlate_1x.stl`](FreeCAD-Files/Assembly/mesh_export/MotorPlate_1x.stl)

### 9.3 Wheel & Axle Components
- [`BackWheelAxle_2x.stl`](FreeCAD-Files/Assembly/mesh_export/BackWheelAxle_2x.stl)
- [`BackWheelConnector_2x.stl`](FreeCAD-Files/Assembly/mesh_export/BackWheelConnector_2x.stl)
- [`BackWheelStopper_2x.stl`](FreeCAD-Files/Assembly/mesh_export/BackWheelStopper_2x.stl)
- [`FrontWheelAxleLeft_1x.stl`](FreeCAD-Files/Assembly/mesh_export/FrontWheelAxleLeft_1x.stl)
- [`FrontWheelAxleRight_1x.stl`](FreeCAD-Files/Assembly/mesh_export/FrontWheelAxleRight_1x.stl)
- [`FrontWheelStopper_2x.stl`](FreeCAD-Files/Assembly/mesh_export/FrontWheelStopper_2x.stl)

### 9.4 Steering Linkages
- [`TBoneLinkageBottom_1x.stl`](FreeCAD-Files/Assembly/mesh_export/TBoneLinkageBottom_1x.stl)
- [`TBoneLinkageTop_1x.stl`](FreeCAD-Files/Assembly/mesh_export/TBoneLinkageTop_1x.stl)
- [`TransferLinkageLeft_1x.stl`](FreeCAD-Files/Assembly/mesh_export/TransferLinkageLeft_1x.stl)
- [`TransferLinkageRight_1x.stl`](FreeCAD-Files/Assembly/mesh_export/TransferLinkageRight_1x.stl)
- [`WheelLinkageBottomLeft_1x.stl`](FreeCAD-Files/Assembly/mesh_export/WheelLinkageBottomLeft_1x.stl)
- [`WheelLinkageBottomRight_1x.stl`](FreeCAD-Files/Assembly/mesh_export/WheelLinkageBottomRight_1x.stl)
- [`WheelLinkageTopLeft_1x.stl`](FreeCAD-Files/Assembly/mesh_export/WheelLinkageTopLeft_1x.stl)
- [`WheelLinkageTopRight_1x.stl`](FreeCAD-Files/Assembly/mesh_export/WheelLinkageTopRight_1x.stl)

### 9.5 Miscellaneous
- [`LidarPlate_1x.stl`](FreeCAD-Files/Assembly/mesh_export/LidarPlate_1x.stl)
<!--TODO:-->

<!--
______________________________________________________________________

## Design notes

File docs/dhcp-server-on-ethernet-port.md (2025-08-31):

# Setting Up a DHCP Server Using Ethernet Port with Internet Connection from Wireless LAN

This guide will show you how to set up your laptop or computer's ethernet port to act as a DHCP server, providing IP addresses and internet access to a connected device through the ethernet interface, while the laptop receives its internet connection via wireless LAN.

## Step 1: Install Required Packages

Before starting, ensure you have `isc-dhcp-server` and `iptables` installed. You can install them by running:

```bash
sudo apt update
sudo apt install isc-dhcp-server iptables-persistent
```

## Step 2: How to Find `YOUR_ETHERNET_INTERFACE` and `YOUR_WIRELESS_INTERFACE`:
To find the name of your interfaces, run the following command:

```bash
ip a
```

Look for the interface name associated with your ethernet connection (it could be something like `enp3s0`, `enp3s0f0`, etc.). Replace all `YOUR_ETHERNET_INTERFACE` in later steps with the name of your ethernet interface.

Then find the name of your wireless interface (it might be `wlp1s0`, `wlan0`, or something similar). Replace all `YOUR_WIRELESS_INTERFACE` in later steps with the name of your wireless interface.

## Step 3: Configure DHCP Server

### 3.1 Edit DHCP Server Configuration
First, configure the DHCP server to listen on your ethernet interface. Run the following command to edit the DHCP server configuration:

```bash
sudo nano /etc/default/isc-dhcp-server
```

Modify the file to look like this:

```bash
INTERFACESv4="YOUR_ETHERNET_INTERFACE"
INTERFACESv6=""
```

Replace `YOUR_ETHERNET_INTERFACE` with the interface name you found [above](#step-2-how-to-find-your_ethernet_interface-and-your_wireless_interface).

### 3.2 Define IP Range and Subnet in DHCP Config
Next, define the IP range and subnet to be used by the DHCP server:

```bash
sudo nano /etc/dhcp/dhcpd.conf
```

Add the following configuration:

```bash
subnet 192.168.39.0 netmask 255.255.255.0 {
  range 192.168.39.10 192.168.39.50;
  option subnet-mask 255.255.255.0;
  option routers 192.168.39.1;
}
```

This configuration will provide IP addresses in the range of `192.168.39.10` to `192.168.39.50`.

## Step 4: Configure Ethernet Interface for Static IP

### 4.1 Add a New Network Connection
Now, you need to add a static IP address to your ethernet interface and configure it to use the DHCP server. Run the following `nmcli` command:

```bash
nmcli connection add type ethernet con-name "DHCP Server" ifname YOUR_ETHERNET_INTERFACE autoconnect yes \
  connection.autoconnect-priority 0 ipv4.method manual ipv4.addresses 192.168.39.1/24 \
  ipv4.route-metric -1 ipv4.may-fail yes ipv4.dhcp-send-hostname yes ipv6.method disabled
```

Replace `YOUR_ETHERNET_INTERFACE` with the interface name you found [above](#step-2-how-to-find-your_ethernet_interface-and-your_wireless_interface).

This assigns the IP `192.168.39.1` to the ethernet interface.

## Step 5: Enable IP Forwarding

### 5.1 Enable IP Forwarding in `sysctl.conf`
To forward internet traffic from your wireless LAN to the ethernet interface, enable IP forwarding by running:

```bash
sudo nano /etc/sysctl.conf
```

Uncomment the line that enables IP forwarding:

```bash
#net.ipv4.ip_forward=1
```

### 5.2 Apply Changes
Apply the changes to the system settings:

```bash
sudo sysctl -p
```

## Step 6: Set Up IP Masquerading

### 6.1 Configure iptables for NAT
Now, use `iptables` to configure Network Address Translation (NAT) so the connected device can use the internet from your wireless connection. Run the following commands:

```bash
sudo iptables -t nat -A POSTROUTING -o YOUR_WIRELESS_INTERFACE -j MASQUERADE
sudo iptables -A FORWARD -i YOUR_ETHERNET_INTERFACE -o YOUR_WIRELESS_INTERFACE -j ACCEPT
sudo iptables -A FORWARD -i YOUR_WIRELESS_INTERFACE -o YOUR_ETHERNET_INTERFACE -m state --state RELATED,ESTABLISHED -j ACCEPT
```

For `YOUR_ETHERNET_INTERFACE` and `YOUR_WIRELESS_INTERFACE`, use the interface names you found [above](#step-2-how-to-find-your_ethernet_interface-and-your_wireless_interface).

### 6.2 Save iptables Rules
To make these changes persistent across reboots, save the iptables configuration:

```bash
sudo netfilter-persistent save
```

## Step 7: Restart Services

### 7.1 Restart DHCP Server
Finally, restart the DHCP server to apply the changes:

```bash
sudo systemctl restart isc-dhcp-server
```

Your laptop's ethernet port is now acting as a DHCP server, providing IP addresses to connected devices and routing internet traffic from your wireless LAN.

## Additional Tip: Prevent Ethernet Power-Down on Battery

If you notice that the ethernet interface (e.g., `enp3s0f0`) doesn't wake up properly when reconnecting the cable, especially on battery power, it may be due to power management putting the NIC into a low-power state.

You can apply this temporary fix to force it to stay on:

```bash
echo on | sudo tee /sys/class/net/YOUR_ETHERNET_INTERFACE/device/power/control
```

This disables the power-saving mode for that ethernet device until the next reboot. Replace `YOUR_ETHERNET_INTERFACE` with your actual ethernet interface if different, use the interface names you found [above](#step-2-how-to-find-your_ethernet_interface-and-your_wireless_interface).

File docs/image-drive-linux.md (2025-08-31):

# How to Image Drive in Linux

To create an image of a drive in Linux, you'll use the `dd` command. Below is a simple guide to calculate the count and perform the imaging.

## 1. Calculate Count

The `count` parameter defines the number of blocks to be copied. To calculate it:

```
count = <size to image> / <block size>
```

For example:
```
count = 6GB / 4MB = 1500
```

In this case, you are copying 6GB of data with a block size of 4MB, which gives a count of 1500.

## 2. Check Disk Space with `df -h`

Before performing any disk imaging, it's a good idea to check the available space on your system and the target drive. You can do this with the `df -h` command:

```
df -h
```

### Explanation:
- `df`: Displays information about disk space usage.
- `-h`: Makes the output human-readable (e.g., showing sizes in GB, MB).
  
This command will show the available space on all mounted filesystems. Make sure your destination drive has enough space to accommodate the image file.

### **Note:** Before using `dd` to copy or restore an image, always verify that the correct drive is selected, as selecting the wrong drive could lead to data loss. You can double-check the device path using `lsblk` or `fdisk -l`.

## 3. To Image a Drive

**Important Note:** Before running the `dd` command, always double-check the `if` and `of` parameters before running the `dd` command to avoid overwriting important data. Double-check with `lsblk` or `fdisk -l` to confirm the device paths.

Use the following command to create an image of the drive:

```
sudo dd if=<your_drive> of=<your_image_file> bs=<your_block_size> count=<your_count> status=progress && sync
```

### Explanation of the Command:
- `if=<your_drive>`: Specifies the input file (your source drive, e.g., `/dev/sda`).
- `of=<your_image_file>`: Specifies the output file (destination for the image, e.g., `/home/garfieldcmix/Desktop/ImageFiles/gfmrpi_gfm-rpi4.img`).
- `bs=<your_block_size>`: Specifies the block size (e.g., `4M` for 4MB).
- `count=<your_count>`: Specifies the number of blocks to copy, which you calculated earlier (e.g., `1500`).
- `status=progress`: Displays progress during the operation.
- `&& sync`: Ensures all data is written to the disk before finishing.

## 4. To Restore the Image to a Drive

**Important Note:** Restoring an image to a drive will overwrite all data on the target drive. Before running the `dd` command, always double-check the `if` and `of` parameters before running the `dd` command to avoid overwriting important data. Double-check with `lsblk` or `fdisk -l` to confirm the device paths.

To restore the image back to a drive, use the following command:

```
sudo dd if=<your_image_file> of=<your_drive> bs=<your_block_size> status=progress && sync
```

### Explanation of the Command:
- `if=<your_image_file>`: Specifies the input image file (e.g., `/home/garfieldcmix/Desktop/ImageFiles/gfmrpi_gfm-rpi4.img`).
- `of=<your_drive>`: Specifies the output drive (e.g., `/dev/sda`).
- `bs=<your_block_size>`: Specifies the block size (e.g., `4M` for 4MB).
- `status=progress`: Displays progress during the operation.
- `&& sync`: Ensures all data is written to the disk before finishing.

## 5. Alternative Method: Using Disk Imager in Linux Mint

1. Open **Disk Image Writer** in Linux Mint.
2. Click the "..." on the top right and select **Restore Disk Image**.
3. Select the image file you want to write.
4. Select the target device.
5. Click "Restore" to begin the process.

This method provides a graphical interface and is simpler if you're not comfortable using the terminal.

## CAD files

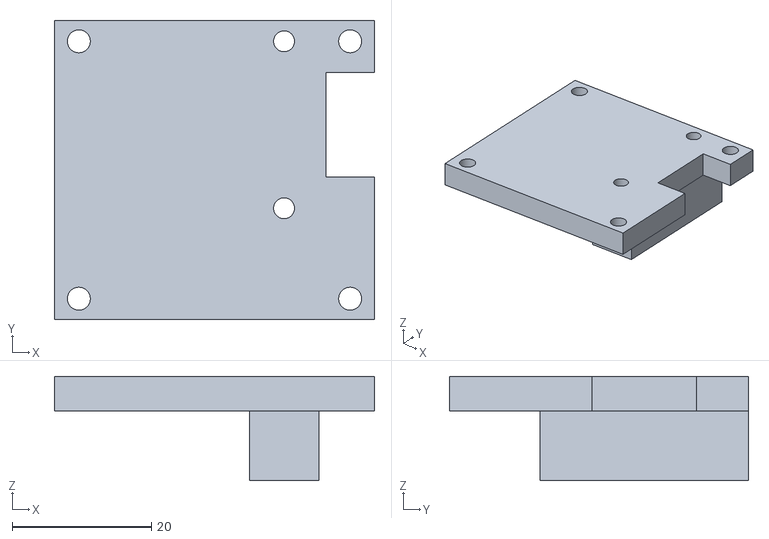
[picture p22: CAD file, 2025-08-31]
FreeCAD-Files/Assembly/mesh_export/MotorPlate_1x.stl
46.0 x 43.0 x 15.0

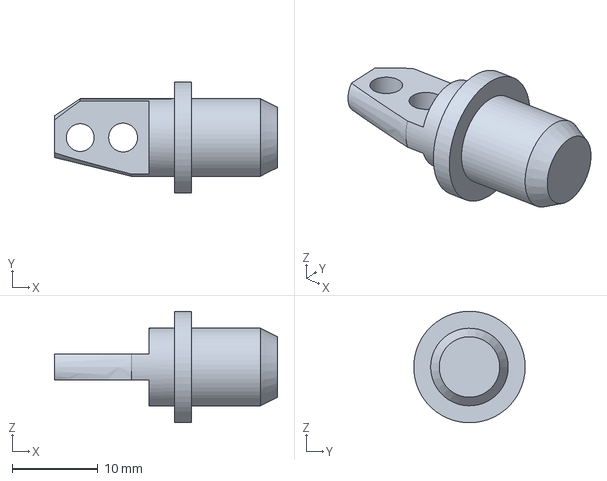
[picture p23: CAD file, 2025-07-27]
FreeCAD-Files/Parts/FrontWheelAxle/FrontWheelAxleRight.FCStd
26.0 x 13.0 x 13.0 mm

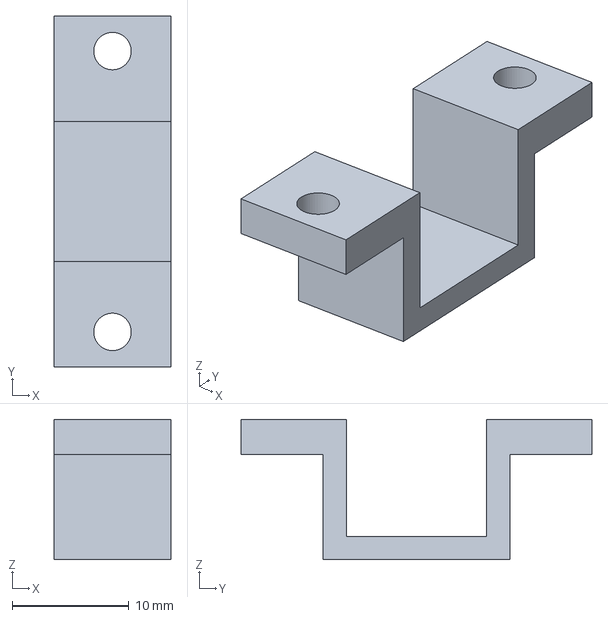
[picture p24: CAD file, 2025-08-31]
FreeCAD-Files/Parts/MotorHolder.FCStd
10.0 x 30.0 x 12.0 mm

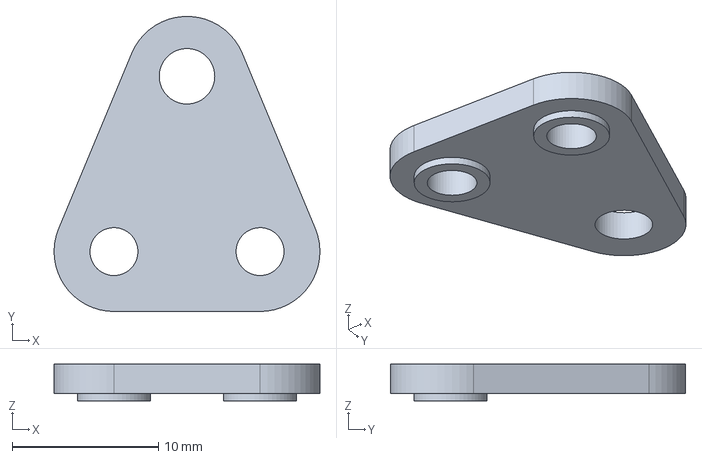
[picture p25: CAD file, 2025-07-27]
FreeCAD-Files/Parts/TBoneLinkage/TBoneLinkageTop.FCStd
18.2 x 20.2 x 2.50 mm

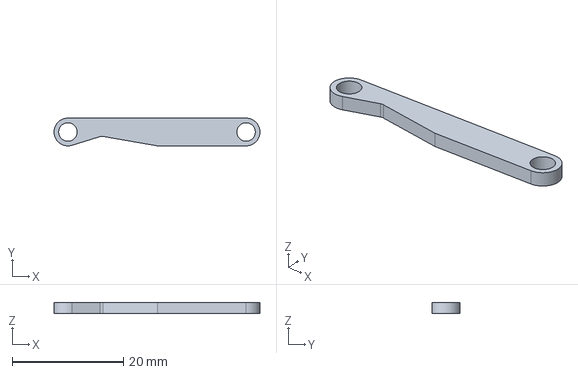
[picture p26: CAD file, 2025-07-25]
FreeCAD-Files/Parts/TransferLinkage/TransferLinkageLeft.FCStd
37.0 x 5.00 x 2.00 mm

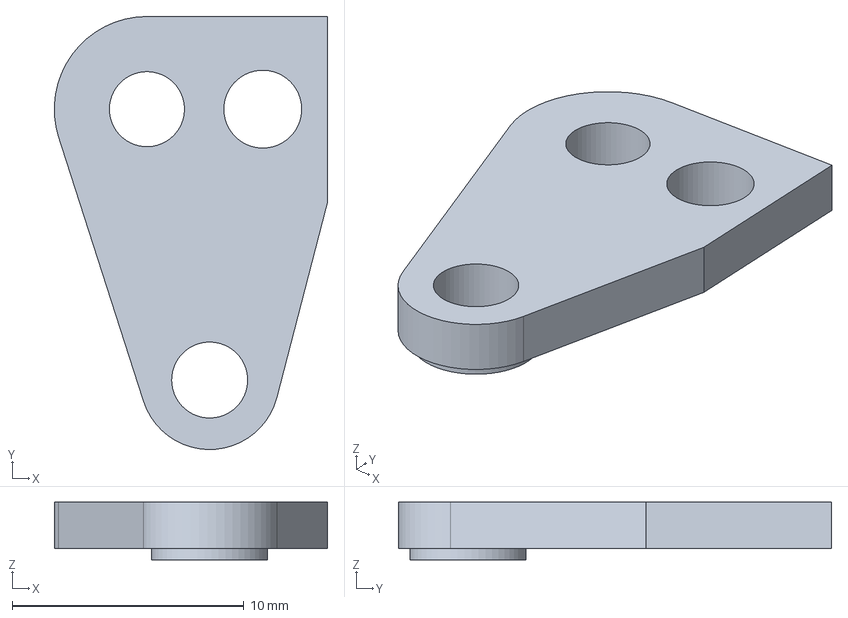
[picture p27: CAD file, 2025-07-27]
FreeCAD-Files/Parts/WheelLinkage/WheelLinkageTopRight.FCStd
11.8 x 18.7 x 2.50 mm

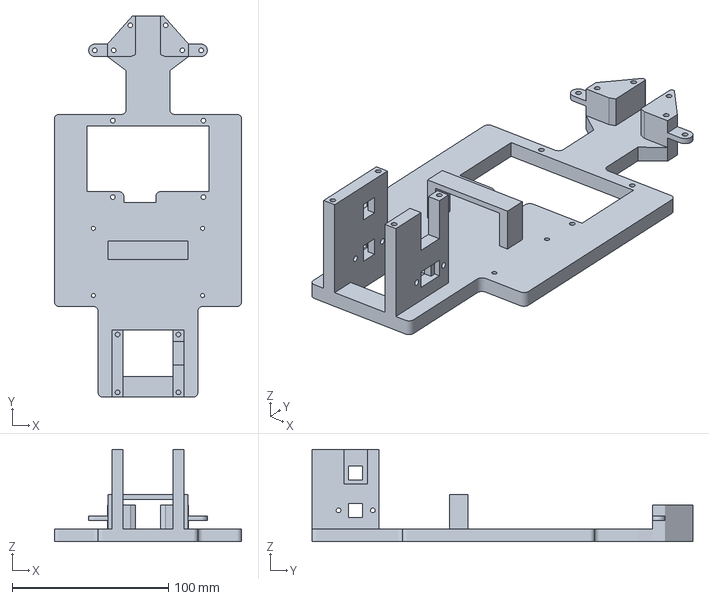
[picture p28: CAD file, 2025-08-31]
Slicer-Files/Bambu_Lab_P1S_(Bambu_Slicer)/Chassis_1x.3mf
120.0 x 244.0 x 59.0 mm

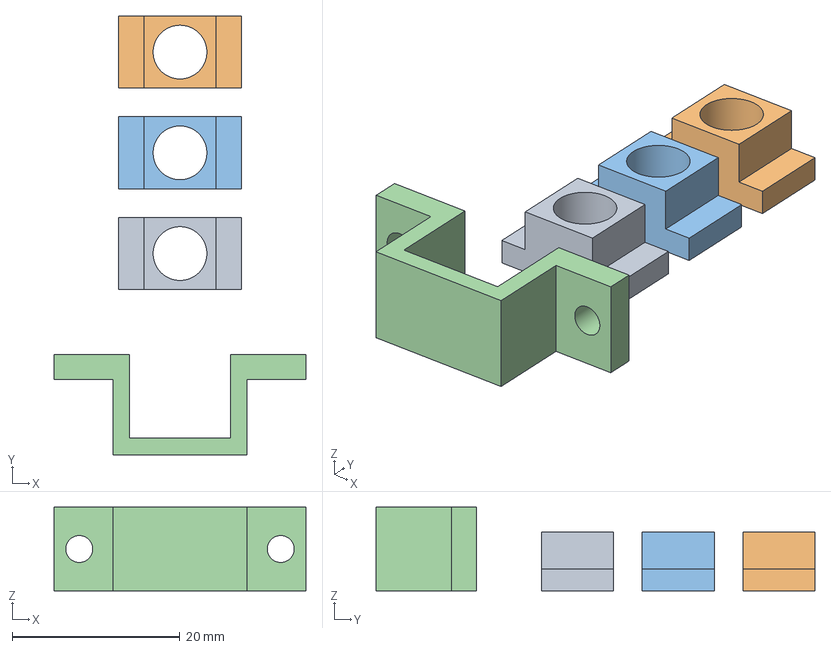
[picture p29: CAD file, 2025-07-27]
Slicer-Files/Ender_3_V3_KE_(Cura_Slicer)/CE3V3KE_AxleHolder_MotorHolder.3mf
30.0 x 52.3 x 10.00 mm
AxleHolder_3x.stl
AxleHolder_3x.stl(1)
AxleHolder_3x.stl(2)
MotorHolder_1x.stl

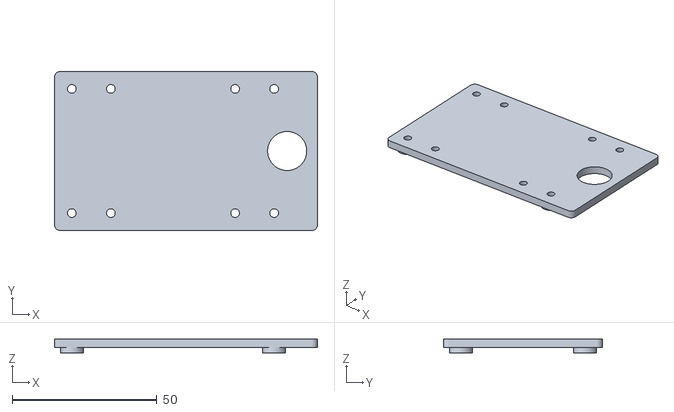
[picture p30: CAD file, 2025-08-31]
FreeCAD-Files/Assembly/mesh_export/LidarPlate_1x.stl
91.0 x 55.0 x 5.00

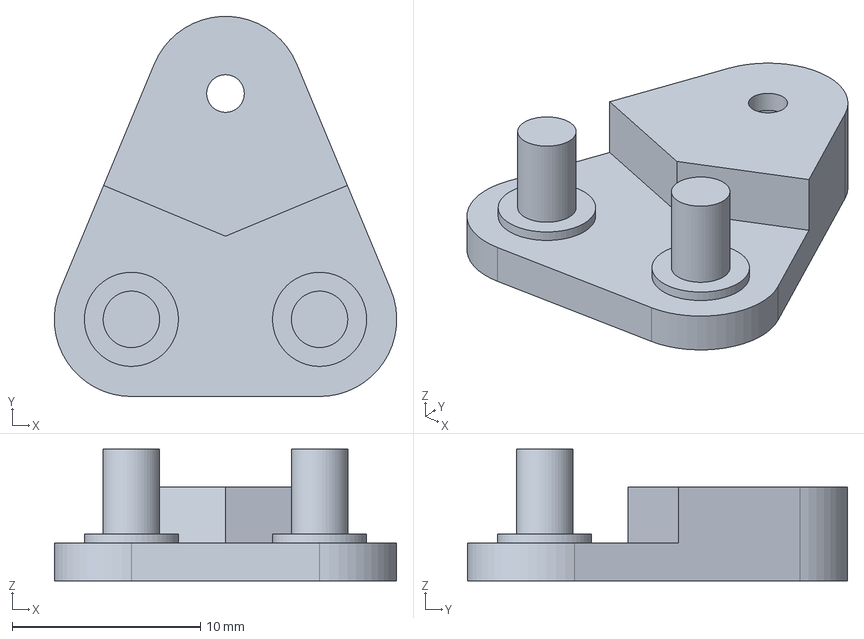
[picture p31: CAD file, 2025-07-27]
FreeCAD-Files/Parts/TBoneLinkage/TBoneLinkageBottom.FCStd
18.2 x 20.2 x 7.00 mm

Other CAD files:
FreeCAD-Files/Assembly/FrontAssembly.FCStd
FreeCAD-Files/Assembly/MainAssembly.FCStd
FreeCAD-Files/Models/SteeringAckermannModel.FCStd
FreeCAD-Files/Parts/Chassis.FCStd
FreeCAD-Files/Parts/FrontWheelAxle/FrontWheelAxleLeft.FCStd
FreeCAD-Files/Parts/TransferLinkage/TransferLinkageRight.FCStd
FreeCAD-Files/Parts/WheelLinkage/WheelLinkageTopLeft.FCStd
Slicer-Files/Ender_3_V3_KE_(Cura_Slicer)/CE3V3KE_MotorPlate_1x.3mf
FreeCAD-Files/Assembly/mesh_export/AxleHolder_3x.stl
FreeCAD-Files/Assembly/mesh_export/BackWheelAxle_2x.stl
FreeCAD-Files/Assembly/mesh_export/BackWheelConnector_2x.stl
FreeCAD-Files/Assembly/mesh_export/BackWheelStopper_2x.stl
FreeCAD-Files/Assembly/mesh_export/Chassis_1x.stl
FreeCAD-Files/Assembly/mesh_export/FrontCover_1x.stl
FreeCAD-Files/Assembly/mesh_export/FrontWheelAxleLeft_1x.stl
FreeCAD-Files/Assembly/mesh_export/FrontWheelAxleRight_1x.stl
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

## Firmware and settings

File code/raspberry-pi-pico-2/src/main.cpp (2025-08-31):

#include <cstdint>
#include <cstdio>
#include <hardware/gpio.h>
#include <pico/time.h>

#include "bno085_controller.h"
#include "encoder_controller.h"
#include "i2c_slave.h"
#include "imu_struct.h"
#include "motor_controller.h"
#include "motor_speed_controller.h"
#include "servo_controller.h"

const uint MOSFET_PIN = 19;

const uint I2C0_SDA_PIN = 4;
const uint I2C0_SCL_PIN = 5;

const uint I2C1_SDA_PIN = 2;
const uint I2C1_SCL_PIN = 3;
const uint I2C1_BAUDRATE = 400000;  // 400 kHz
const uint I2C1_SLAVE_ADDR = 0x39;

const uint MOTOR_IN1_PIN = 6;
const uint MOTOR_IN2_PIN = 7;

const uint ENCODER_A_PIN = 10;
const uint ENCODER_B_PIN = 11;
const int ENCODER_PULSE_PER_REV = 28;
const int ENCODER_GEAR_RATIO = 100;

const uint SERVO_PIN = 15;
const float SERVO_MAX_ANGLE = 90.0f;
const uint16_t SERVO_MIN_PULSE_US = 1000;
const uint16_t SERVO_MAX_PULSE_US = 2000;
const uint16_t SERVO_FREQ_HZ = 50;

const float STEERING_MIN_ANGLE = 0.0f;
const float STEERING_MAX_ANGLE = 86.5f;

float toSteeringAngle(float steeringPercent) {
    const float inMin = -100.0f;
    const float inMax = 100.0f;
    const float outMin = STEERING_MIN_ANGLE;
    const float outMax = STEERING_MAX_ANGLE;

    float output = outMin + (steeringPercent - inMin) * (outMax - outMin) / (inMax - inMin);
    return output;
}

int main() {
    gpio_init(MOSFET_PIN);
    gpio_set_dir(MOSFET_PIN, GPIO_OUT);

    gpio_put(MOSFET_PIN, 1);

    stdio_init_all();

    Bno085Controller imu(i2c0, I2C0_SDA_PIN, I2C0_SCL_PIN);

    i2c_slave::contextInit();
    i2c_slave::i2cInit(i2c1, I2C1_SLAVE_ADDR, I2C1_SDA_PIN, I2C1_SCL_PIN, I2C1_BAUDRATE);

    MotorController motor(MOTOR_IN1_PIN, MOTOR_IN2_PIN);
    EncoderController encoder(ENCODER_A_PIN, ENCODER_B_PIN, ENCODER_PULSE_PER_REV, ENCODER_GEAR_RATIO);
    MotorSpeedController motorPid(motor, encoder);

    ServoController servo(SERVO_PIN, SERVO_MAX_ANGLE, SERVO_MIN_PULSE_US, SERVO_MAX_PULSE_US, SERVO_FREQ_HZ);

    motor.begin();
    encoder.begin();
    motorPid.setTargetRPS(0.0);

    servo.begin();
    servo.setAngle(toSteeringAngle(0.0f));

    while (!imu.begin()) {
        sleep_ms(1000);
    }

    imu.setCalibrationConfig(0b0000000);
    sleep_ms(1000);

    i2c_slave::setIsRunning(false);
    i2c_slave::setIsImuReady(true);

    imu.enableRotation(8);
    imu.enableAccelerometer(8);

    ImuAccel accel;
    ImuEuler euler;

    double motorSpeed = 1001.0;
    float steeringPercent = 0.0f;

    uint32_t lastImuUpdate = 0;
    const uint32_t imuInterval = 4;

    uint32_t lastMotorPidUpdate = 0;
    const uint32_t motorPidInterval = 8;
    while (true) {
        uint32_t now = to_ms_since_boot(get_absolute_time());

        i2c_slave::setIsRunning(true);

        if (now - lastImuUpdate >= imuInterval) {
            if (imu.wasReset()) {
                imu.enableRotation(10);
                imu.enableAccelerometer(10);
            }

            if (imu.update(accel, euler)) {
                i2c_slave::setImuData(accel, euler);
                // printf("Euler angles: H: %.2f°, P: %.2f°, R: %.2f°\n", euler.h, euler.p, euler.r);
            }

            lastImuUpdate = now;
        }

        i2c_slave::setEncoderAngle(encoder.getAngle());

        i2c_slave::getMovementInfo(motorSpeed, steeringPercent);

        if (now - lastMotorPidUpdate >= motorPidInterval) {
            // TODO: Make this a proper protocol
            if (motorSpeed >= 1002.0) {
                motorPid.setTargetRPS(0.0);
                motor.stop(true);
            } else if (motorSpeed >= 1001.0) {
                motorPid.setTargetRPS(0.0);
                motor.stop(false);
            } else {
                motorPid.setTargetRPS(motorSpeed);
            }

            motorPid.update();
            lastMotorPidUpdate = now;
        }

        servo.setAngle(toSteeringAngle(steeringPercent));

        // printf("%.2f\n", motorPid.getPower());

        tight_loop_contents();
    }

    while (true)
        tight_loop_contents();
}

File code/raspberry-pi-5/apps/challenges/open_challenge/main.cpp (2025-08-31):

#include "combined_processor.h"
#include "lidar_module.h"
#include "lidar_processor.h"
#include "pico2_module.h"
#include "pid_controller.h"

#include <atomic>
#include <chrono>
#include <csignal>
#include <iostream>
#include <optional>
#include <thread>

volatile std::sig_atomic_t stop_flag = 0;

void signalHandler(int signum) {
    std::cout << "\nInterrupt signal (" << signum << ") received.\n";
    stop_flag = 1;
}

const float TARGET_OUTER_WALL_DISTANCE = 0.50f;

const float PRE_TURN_FRONT_WALL_DISTANCE = 1.20f;
const auto PRE_TURN_COOLDOWN = std::chrono::milliseconds(1500);

const float TURNING_FRONT_WALL_DISTANCE = 0.85f;

const float STOP_FRONT_WALL_DISTANCE = 1.80f;
const auto STOP_DELAY = std::chrono::milliseconds(100);

enum Mode
{
    NORMAL,
    PRE_TURN,
    TURNING,
    PRE_STOP,
    STOP
};

struct State {
    PIDController headingPid{3.0f, 0.0, 0.0f};
    PIDController wallPid{180.0f, 0.0, 0.0f};

    std::optional<float> initialHeading;
    std::optional<RotationDirection> robotTurnDirection;

    Mode robotMode = Mode::NORMAL;
    int numberOfTurn = 0;
    Direction headingDirection = Direction::NORTH;
};

void update(float dt, LidarModule &lidar, Pico2Module &pico2, State &state, float &outMotorSpeed, float &outSteeringPercent) {
    std::vector<TimedLidarData> timedLidarDatas;
    lidar.getAllTimedLidarData(timedLidarDatas);
    if (timedLidarDatas.empty()) return;

    std::vector<TimedPico2Data> timedPico2Datas;
    pico2.getAllTimedData(timedPico2Datas);
    if (timedPico2Datas.empty()) return;

    auto &timedLidarData = timedLidarDatas[timedLidarDatas.size() - 1];
    auto &timedPico2Data = timedPico2Datas[timedPico2Datas.size() - 1];

    auto now = std::chrono::steady_clock::now();

    auto filteredLidarData = lidar_processor::filterLidarData(timedLidarData);

    auto deltaPose = combined_processor::aproximateRobotPose(filteredLidarData, timedPico2Datas);

    // std::cout << "[DeltaPose] ΔX: " << deltaPose.deltaX << " m, ΔY: " << deltaPose.deltaY << " m, ΔH: " << deltaPose.deltaH << " deg"
    //           << std::endl;

    if (not state.initialHeading) state.initialHeading = timedPico2Data.euler.h;

    float heading = timedPico2Data.euler.h - state.initialHeading.value_or(0.0f);
    heading = std::fmod(heading, 360.0f);
    if (heading < 0.0f) heading += 360.0f;

    auto lineSegments = lidar_processor::getLines(filteredLidarData, deltaPose, 0.05f, 10, 0.10f, 0.10f, 18.0f, 0.20f);
    auto relativeWalls = lidar_processor::getRelativeWalls(lineSegments, state.headingDirection, heading, 0.30f, 25.0f, 0.22f);
    auto resolveWalls = lidar_processor::resolveWalls(relativeWalls);

    // Set robotTurnDirection
    if (!state.robotTurnDirection) {
        auto newRobotTurnDirection = lidar_processor::getTurnDirection(relativeWalls);
        if (newRobotTurnDirection) state.robotTurnDirection = newRobotTurnDirection;
    }

    auto frontWall = resolveWalls.frontWall;
    auto backWall = resolveWalls.backWall;

    std::optional<lidar_processor::LineSegment> outerWall;
    std::optional<lidar_processor::LineSegment> innerWall;

    if (state.robotTurnDirection) {
        if (*state.robotTurnDirection == RotationDirection::CLOCKWISE) {
            outerWall = resolveWalls.leftWall;
            innerWall = resolveWalls.rightWall;
        } else {
            outerWall = resolveWalls.rightWall;
            innerWall = resolveWalls.leftWall;
        }
    }

instant_update:
    switch (state.robotMode) {
    default:
        std::cout << "[OpenChallenge] Invalid Mode!" << std::endl;
        stop_flag = 1;
        return;

    case Mode::NORMAL: {
        // std::cout << "[Mode::NORMAL]\n";

        if (state.numberOfTurn == 12) {
            state.robotMode = Mode::PRE_STOP;
            goto instant_update;
        }

        static auto lastPreTurnTrigger = std::chrono::steady_clock::now() - PRE_TURN_COOLDOWN;
        if (frontWall && frontWall->perpendicularDistance(0.0f, 0.0f) <= PRE_TURN_FRONT_WALL_DISTANCE &&
            (now - lastPreTurnTrigger) >= PRE_TURN_COOLDOWN)
        {
            state.robotMode = Mode::PRE_TURN;
            lastPreTurnTrigger = now;
            goto instant_update;
        }
        outMotorSpeed = 4.5f;
        break;
    }
    case Mode::PRE_TURN: {
        // std::cout << "[Mode::PRE_TURN]\n";

        if (frontWall && frontWall->perpendicularDistance(0.0f, 0.0f) <= TURNING_FRONT_WALL_DISTANCE) {
            Direction nextHeadingDirection;
            if (state.robotTurnDirection.value_or(RotationDirection::CLOCKWISE) == RotationDirection::CLOCKWISE) {
                float nextHeading = state.headingDirection.toHeading() + 90.0f;
                nextHeading = std::fmod(nextHeading + 360.0f, 360.0f);
                nextHeadingDirection = Direction::fromHeading(nextHeading);
            } else {
                float nextHeading = state.headingDirection.toHeading() - 90.0f;
                nextHeading = std::fmod(nextHeading + 360.0f, 360.0f);
                nextHeadingDirection = Direction::fromHeading(nextHeading);
            }

            state.headingDirection = nextHeadingDirection;

            state.robotMode = Mode::TURNING;
            goto instant_update;
        }

        outMotorSpeed = 4.5f;
        break;
    }
    case Mode::TURNING: {
        // std::cout << "[Mode::TURNING]\n";

        if (std::abs(state.headingDirection.toHeading() - heading) <= 20.0f) {
            state.numberOfTurn++;
            state.robotMode = Mode::NORMAL;
            goto instant_update;
        }

        outMotorSpeed = 4.5f;
        break;
    }
    case Mode::PRE_STOP: {
        // std::cout << "[Mode::PRE_STOP]\n";

        static bool stopTimerActive = false;
        static auto stopStartTime = std::chrono::steady_clock::now();
        if (!stopTimerActive) {
            stopTimerActive = true;
            stopStartTime = std::chrono::steady_clock::now();
        }

        auto elapsed = std::chrono::steady_clock::now() - stopStartTime;
        if (frontWall && frontWall->perpendicularDistance(0.0f, 0.0f) <= STOP_FRONT_WALL_DISTANCE && elapsed >= STOP_DELAY) {
            stopTimerActive = false;

            state.robotMode = Mode::STOP;
            goto instant_update;
        }
        outMotorSpeed = 4.5f;

        break;
    }
    case Mode::STOP: {
        // std::cout << "[Mode::STOP]\n";
        outMotorSpeed = 0.0f;
        outSteeringPercent = 0.0f;

        stop_flag = 1;
        return;
    }
    }

    // NOTE: Use break and it will run the pid
    // If don't want to run the pid then use return

    float wallError = 0.0f;
    if (outerWall) {
        wallError = outerWall->perpendicularDistance(0.0f, 0.0f) - TARGET_OUTER_WALL_DISTANCE;
    }
    float headingErrorOffset = state.wallPid.update(wallError, dt);
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

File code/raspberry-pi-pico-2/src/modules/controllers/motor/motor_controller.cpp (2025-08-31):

#include "motor_controller.h"

#include <hardware/gpio.h>
#include <hardware/pwm.h>

MotorController::MotorController(uint pinIn1, uint pinIn2)
    : pinIn1_(pinIn1)
    , pinIn2_(pinIn2) {}

void MotorController::begin() {
    // Set IN1 as PWM
    gpio_set_function(pinIn1_, GPIO_FUNC_PWM);
    sliceIn1_ = pwm_gpio_to_slice_num(pinIn1_);
    channelIn1_ = pwm_gpio_to_channel(pinIn1_);

    pwm_set_wrap(sliceIn1_, 1000);  // 0–1000 duty cycle
    pwm_set_chan_level(sliceIn1_, channelIn1_, 0);
    pwm_set_enabled(sliceIn1_, true);

    // Set IN2 as PWM
    gpio_set_function(pinIn2_, GPIO_FUNC_PWM);
    sliceIn2_ = pwm_gpio_to_slice_num(pinIn2_);
    channelIn2_ = pwm_gpio_to_channel(pinIn2_);

    pwm_set_wrap(sliceIn2_, 1000);
    pwm_set_chan_level(sliceIn2_, channelIn2_, 0);
    pwm_set_enabled(sliceIn2_, true);
}

void MotorController::setPower(float power) {
    if (power > 100.0f) power = 100.0f;
    if (power < -100.0f) power = -100.0f;

    if (power > 0) {
        // Forward: PWM on IN1, IN2 = 0
        updatePwm(pinIn1_, sliceIn1_, channelIn1_, power / 100.0f);
        updatePwm(pinIn2_, sliceIn2_, channelIn2_, 0.0f);
    } else if (power < 0) {
        // Reverse: PWM on IN2, IN1 = 0
        updatePwm(pinIn1_, sliceIn1_, channelIn1_, 0.0f);
        updatePwm(pinIn2_, sliceIn2_, channelIn2_, -power / 100.0f);
    } else {
        // Stop (coast)
        updatePwm(pinIn1_, sliceIn1_, channelIn1_, 0.0f);
        updatePwm(pinIn2_, sliceIn2_, channelIn2_, 0.0f);
    }
}

void MotorController::stop(bool brake) {
    if (brake) {
        // Brake: both high
        updatePwm(pinIn1_, sliceIn1_, channelIn1_, 1.0f);
        updatePwm(pinIn2_, sliceIn2_, channelIn2_, 1.0f);
    } else {
        // Coast: both low
        updatePwm(pinIn1_, sliceIn1_, channelIn1_, 0.0f);
        updatePwm(pinIn2_, sliceIn2_, channelIn2_, 0.0f);
    }
}

void MotorController::updatePwm(uint pin, uint slice, uint channel, float duty) {
    uint level = static_cast<uint>(duty * 1000.0f);
    pwm_set_chan_level(slice, channel, level);
}

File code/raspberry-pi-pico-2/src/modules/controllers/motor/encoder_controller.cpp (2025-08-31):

#include "encoder_controller.h"

#include <hardware/gpio.h>

// Static instance pointer
EncoderController *EncoderController::instance_ = nullptr;

// Constructor
EncoderController::EncoderController(uint pinA, uint pinB, int pulsesPerRev, int gearRatio)
    : pinA_(pinA)
    , pinB_(pinB)
    , pulsesPerRev_(pulsesPerRev)
    , gearRatio_(gearRatio)
    , lastEncoded_(0)
    , encoderValue_(0) {}

// Initialize GPIO and interrupts
void EncoderController::begin() {
    instance_ = this;

    // Configure pins
    gpio_init(pinA_);
    gpio_set_dir(pinA_, GPIO_IN);
    gpio_pull_up(pinA_);

    gpio_init(pinB_);
    gpio_set_dir(pinB_, GPIO_IN);
    gpio_pull_up(pinB_);

    // Initialize lastEncoded
    int MSB = gpio_get(pinA_);
    int LSB = gpio_get(pinB_);
    lastEncoded_ = (MSB << 1) | LSB;

    // Setup interrupts
    gpio_set_irq_enabled_with_callback(pinA_, GPIO_IRQ_EDGE_RISE | GPIO_IRQ_EDGE_FALL, true, &encoderISR);
    gpio_set_irq_enabled(pinB_, GPIO_IRQ_EDGE_RISE | GPIO_IRQ_EDGE_FALL, true);
}

// Return raw encoder count
long EncoderController::getCount() const {
    return encoderValue_.load();
}

// Return angle in degrees (float)
double EncoderController::getAngle() const {
    return encoderValue_.load() * (360.0 / (pulsesPerRev_ * gearRatio_));
}

// Reset encoder
void EncoderController::reset() {
    encoderValue_ = 0;
}

// Static ISR wrapper
void EncoderController::encoderISR(uint gpio, uint32_t events) {
    if (instance_) instance_->handleInterrupt();
}

// Actual ISR logic
void EncoderController::handleInterrupt() {
    int MSB = gpio_get(pinA_);
    int LSB = gpio_get(pinB_);

    int encoded = (MSB << 1) | LSB;
    int sum = (lastEncoded_ << 2) | encoded;

    if (sum == 0b1101 || sum == 0b0100 || sum == 0b0010 || sum == 0b1011) encoderValue_--;
    if (sum == 0b1110 || sum == 0b0111 || sum == 0b0001 || sum == 0b1000) encoderValue_++;

    lastEncoded_ = encoded;
}

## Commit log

2025-07-10 Add SteeringAckermannModel
    [SteeringAckermannModel.FCStd]
2025-07-10 Add Chassis Part
    [Chassis.FCStd, SteeringAckermannModel.FCStd]
2025-07-10 Change Chassis Color
    [Chassis.FCStd]
2025-07-10 Add front part of the Chassis
    [Chassis.FCStd]
2025-07-10 Add back part of the Chassis
    [Chassis.FCStd]
2025-07-10 Add raspberry pi 5 hole to Chassis
    [Chassis.FCStd]
2025-07-10 Add raspberry pi pico holder to Chassis
    [Chassis.FCStd]
2025-07-10 Add hole for lidar to Chassis
    [Chassis.FCStd]
2025-07-10 Add MotorPlate Part
    [MotorPlate.FCStd]
2025-07-10 Add MotorHolder Part
    [MotorHolder.FCStd]
2025-07-10 Add Motor Gear Part
    [MotorGear.FCStd]
2025-07-10 Change parts color
    [MotorGear.FCStd, MotorHolder.FCStd, MotorPlate.FCStd]
2025-07-10 Add AxleHolder Part
    [AxleHolder.FCStd]
2025-07-10 Add BackWheelAxle Part
    [BackWheelAxle.FCStd]
2025-07-10 Add BackWheelConnector Part
    [BackWheelConnector.FCStd]
2025-07-10 Add BackWheelStopper Part
    [BackWheelStopper.FCStd]
2025-07-10 Add LidarPlate Part
    [LidarPlate.FCStd]
2025-07-12 Add FrontCover Part
    [FrontCover.FCStd]
2025-07-14 Change FrontCover Part
    [FrontCover.FCStd]
2025-07-15 Add TBoneLinkageBottom Part
    [TBoneLinkageBottom.FCStd]
2025-07-15 Add TBoneLinkageTop Part
    [TBoneLinkageTop.FCStd]
2025-07-19 Add TransferLinkageLeft Part
    [TransferLinkageLeft.FCStd]
2025-07-19 Add TransferLinkageRight Part
    [TransferLinkageRight.FCStd]
2025-07-19 Add WheelLinkageBottomLeft Part
    [WheelLinkageBottomLeft.FCStd]
2025-07-19 Add WheelLinkageTopLeft Part
    [WheelLinkageTopLeft.FCStd]
2025-07-21 Add FrontWheelAxleLeft Part
    [FrontWheelAxleLeft.FCStd]
2025-07-21 Add FrontWheelStopper Part
    [FrontWheelStopper.FCStd]
2025-07-21 Add mirrored parts
    [FrontWheelAxleRight.FCStd, WheelLinkageBottomRight.FCStd, WheelLinkageTopRight.FCStd]
2025-07-23 Add N20Motor Part
    [N20Motor.FCStd]
2025-07-23 Add LegoDifferentialGear Part
    [LegoDifferentialGear.FCStd]
2025-07-23 Add LegoBevelGear Part
    [LegoBevelGear.FCStd]
2025-07-23 Add RpiCamera Part
    [RpiCamera.FCStd]
2025-07-23 Add S0004 Part
    [S0004m.FCStd]
2025-07-23 Add RPLidarC1 Part
    [RPLidarC1.FCStd]
2025-07-23 Add RaspberryPiUpsHat Part
    [RaspberryPiUpsHat.FCStd]
2025-07-23 Add RaspberryPi5M2Hat Part
    [RaspberryPi5M2Hat.FCStd]
2025-07-23 Use STEP instead of STL for LegoBevelGear Part
    [LegoBevelGear.FCStd]
2025-07-23 Change LegoBevelGear Part
    [LegoBevelGear.FCStd]
2025-07-23 Add Wheel Part
    [Wheel.FCStd]
2025-07-23 Add back part to the MainAssembly
    [MainAssembly.FCStd]
2025-07-23 Correct the TBoneLinkageBottom Part name
    [TBoneLinkageBottom.FCStd]
2025-07-23 Update TBoneLinkageTop Part
    [TBoneLinkageTop.FCStd]
2025-07-23 Done MainAssembly
    [MainAssembly.FCStd]
2025-07-25 Make TBoneLinkage bigger to limit the max angle of the servo
    [TBoneLinkageBottom.FCStd, TBoneLinkageTop.FCStd]
2025-07-25 Update MainAssembly
    [MainAssembly.FCStd]
2025-07-25 Update TBoneLinkage
    [MainAssembly.FCStd, TBoneLinkageBottom.FCStd, TBoneLinkageTop.FCStd]
2025-07-25 Add tolerance for M3 screw in MotorPlate and MotorHolder
    [MainAssembly.FCStd, MotorHolder.FCStd, MotorPlate.FCStd]
2025-07-25 Add tolerance for fitting in WheelLinkage and FrontWheelAxle
    [FrontWheelAxleLeft.FCStd, FrontWheelAxleRight.FCStd, MainAssembly.FCStd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]
2025-07-25 Add BatchMeshExport
    [AxleHolder_3x.stl, BackWheelAxle_2x.stl, BackWheelConnector_2x.stl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]
2025-07-25 Fix tolerance for linkages
    [FrontWheelAxleLeft.FCStd, FrontWheelAxleLeft_1x.stl, FrontWheelAxleRight.FCStd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]
2025-07-25 Slice linkages
    [CE3V3KE_Linkages.3mf]
2025-07-25 Slice FrontCover
    [CE3V3KE_FrontCover_1x.3mf]
2025-07-25 Slice BackWheelStuff
    [CE3V3KE_BackWheelStuff.3mf]
2025-07-25 Fix tolerance
    [FrontWheelAxleLeft.FCStd, FrontWheelAxleLeft_1x.stl, FrontWheelAxleRight.FCStd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]
2025-07-26 Change Cura slicer settings
    [CE3V3KE_Linkages.3mf]
2025-07-26 Seperate FrontAssembly from MainAssembly
    [BackWheelStopper.FCStd, FrontAssembly.FCStd, MainAssembly.FCStd]
2025-07-26 Regenerate the STL files
    [AxleHolder_3x.stl, BackWheelAxle_2x.stl, BackWheelConnector_2x.stl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]
2025-07-26 Fix Linkages 3D print not sticking to the bed
    [CE3V3KE_Linkages.3mf]
2025-07-26 Remove old mesh_export
    [AxleHolder_3x.stl, BackWheelAxle_2x.stl, BackWheelConnector_2x.stl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]
2025-07-26 Fix FrontCover servo holes
    [FrontAssembly.FCStd, FrontCover.FCStd, MainAssembly.FCStd]
2025-07-27 Change Cura slicer settings for FrontCover
    [CE3V3KE_FrontCover_1x.3mf, FrontCover_1x.stl]
2025-07-27 Increase tolerance for FrontWheelAxle
    [FrontAssembly.FCStd, FrontWheelAxleLeft.FCStd, FrontWheelAxleLeft_1x.stl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]
2025-07-27 Update TBoneLinkageBottom
    [FrontAssembly.FCStd, MainAssembly.FCStd, TBoneLinkageBottom.FCStd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]
2025-07-27 Update Linkages Cura slicer
    [CE3V3KE_Linkages.3mf, MainAssembly.FCStd]
2025-07-27 Increase torelance for WheelLinkages
    [CE3V3KE_Linkages.3mf, FrontAssembly.FCStd, FrontWheelAxleLeft.FCStd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]
2025-07-27 Fix BackWheelStuff Cura settings
    [CE3V3KE_BackWheelStuff.3mf]
2025-07-27 Increase tolerance for WheelLinkage
    [FrontAssembly.FCStd, MainAssembly.FCStd, WheelLinkageBottomLeft.FCStd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]
2025-07-27 Update Cura project
    [CE3V3KE_BackWheelStuff.3mf, CE3V3KE_FrontCover_1x.3mf, CE3V3KE_Linkages.3mf]
2025-07-27 Update BackWheelStuff
    [CE3V3KE_BackWheelStuff.3mf]
2025-07-27 Add MotorHolder to Cura project
    [CE3V3KE_AxleHolder_3x.3mf, CE3V3KE_AxleHolder_MotorHolder.3mf]
2025-07-27 Add MotorPlate to Cura project
    [CE3V3KE_MotorPlate_1x.3mf]
2025-07-27 Remove support
    [CE3V3KE_AxleHolder_MotorHolder.3mf]
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2025-08-13 Fix camera_module error message
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2025-08-14 Fix the lidar_module so that getData and waitForData output TimedLidarData
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2025-08-14 Fix lidar_processor visualizeLidarData
2025-08-14 Make lider_processor draw lidar into cv::Mat instead of creating a new one
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2025-08-19 Change Chassis so that the rpi5 point the other direction
    [Chassis.FCStd, Chassis_1x.stl, FrontAssembly.FCStd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]
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2025-08-21 Fix Chassis lidar screw hole too small and add bambu slicer files
    [CE3V3KE_AxleHolder_MotorHolder.3mf, CE3V3KE_BackWheelStuff.3mf, CE3V3KE_FrontCover_1x.3mf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]
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2025-08-21 Fix lidar_module include_directories
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2025-08-24 Use reference instead of raw pointer and fix naming convention
    [i2c_slave.cpp, main.cpp]
2025-08-24 Rename structs in imu_struct to have correct name
    [bno085_controller.cpp, i2c_master.cpp, i2c_slave.cpp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]
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2025-08-25 Fix i2c_slave
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2025-08-27 Fix pico 2 bno085 stuck
    [main.cpp]
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2025-08-29 Fix bno085 gyro drift
    [bno085_controller.cpp, main.cpp]
2025-08-29 Make the headingErrorOffset correct sign
    [main.cpp]
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2025-08-29 Fix pico2_module logger_ not initialize
    [pico2_module.cpp]
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2025-08-30 Add space for seam for MotorGear
    [LidarPlate_1x.stl, MainAssembly.FCStd, MotorGear.FCStd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]
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2025-08-30 Change gear dimemsion
    [MainAssembly.FCStd, MotorGear.FCStd]
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
